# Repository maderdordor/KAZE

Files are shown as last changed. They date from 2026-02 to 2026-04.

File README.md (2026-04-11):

CA: 3cUMqT5T8D4mEt9MVRUVgqsDuGgFmjukQGpeQ2eNpump
___





KAZE-cover
___

**Greetings, from your new best friend.**

KAZE is an accessible Open-Source robotics project based on the ESP32 microcontroller system, with an emphasis on expression and movement. 
This project is designed for makers and engineers of all skill levels! KAZE offers a dynamic platform designed to start working with walking robots. 
To build a KAZE robot, you will need basic soldering skills, $50-60 in hardware components, access to a 3D printer, and a basic understanding of Arduino IDE.

This repository contains the CAD design files, STL files, build and wiring guides, and the base/expanded firmware for the ESP32-based controller. 
There is also some included debugging firmware that may be helpful in getting your KAZE up and running.

## Features

*   **Quadruped Design:** Uses 8 servo motors (2 per leg) to achieve roughly 8 total degrees of freedom.
*   **Emotive Display:** Features a 128x64 OLED screen acting as a reactive face that syncs with movement.
*   **Fully Printable:** Designed entirely for 3D printing in PLA with minimal supports.
*   **Network Connectivity:** Connect to your WiFi network for remote control and API access.
*   **JSON API:** RESTful API for programmatic control from Python, JavaScript, and more.
*   **Conversational Faces:** Expressive emotion library with talk variants for voice assistant projects.
*   **KAZE Studio:** New animation composer software to easily create custom movements.
*   **KAZE Companion App:** Python application for voice control and advanced interactions.
*   **Serial CLI:** Control the robot and trigger animations via a Serial Command Line Interface or the web UI.
*   **Pre-programmed Emotes:** Includes animations for Walking, Waving, Dancing, Pointing, Resting, and more.

## Join the Discord community
[https://discord.gg/JcFEPBbtEj
](https://discord.gg/JcFEPBbtEj)
___

## Getting Started

Follow these steps to build your own KAZE Robot:

### 1. Gather Parts 
Check the **[Bill of Materials (BOM)](hardware/bom/README.md)** for a complete list of required electronics and hardware.
*   Microcontroller: Lolin S2 Mini (recommended for DIY builds), KAZE Distro Board V2 (included in Build Kits, pre-flashed), or ESP32-DevKitC-32E with Distro Board V1 (legacy)
*   Actuators: 8x MG90 Servos
*   Power: 5V 3A source (USB-C PD for S2 Mini and V2 Distro Board, or battery + buck converter; see BOM for the 2× 10440 Li-ion + 2× AAA holder option)

### 2. Print Parts 
Download the STLs and follow the **[Printing Guide](hardware/printing/README.md)**.
*   Designed for PLA
*   Minimal supports required

### 3. Build & Wire 
Follow the **[Build Guide](docs/build-guide/README.md)** and **[Wiring Guide](docs/wiring-guide/README.md)** to assemble the frame and connect the electronics.

### 4. Flash Firmware 
Upload the code from the **[Firmware Directory](firmware/README.md)**.
*   Requires Arduino IDE
*   Configure WiFi AP settings

### 5. Create Animations 
Use **[KAZE Studio](software/KAZE-studio/README.md)** to visually design poses and sequences for your robot.

KAZE-wakeup-gif

---

## Software & Firmware

### KAZE Studio
KAZE Studio is a standalone desktop application included in `software/KAZE-studio/`. It allows you to:
*   Visually pose the robot using a schematic interface.
*   Generate C++ code for servo angles automatically.
*   Sequence frames into complex animations.

[**> Go to KAZE Studio**](software/KAZE-studio/README.md)

### KAZE Simulator
The KAZE Simulator, created by Jay Li, is a Rust-based 3D simulation environment for testing KAZE's movements and kinematics in a virtual space. It features:
*   **Physics-based Simulation:** Test walking and balance without hardware.
*   **Web-based Interface:** Run the simulator directly in your browser.
*   **URDF Integration:** Accurate modeling of KAZE's physical properties.

[**> Go to KAZE Simulator**](https://one-for-all.github.io/KAZE-robot-sim/)

### KAZE Companion App
The KAZE Companion App is a Python-based application that enables advanced control and interaction with your robot over your local network. It leverages the new JSON API and network mode features to provide:
*   **Voice Assistant Integration:** Control KAZE with voice commands and see real-time emotional expressions.
*   **Remote Control:** Command your robot from anywhere on your local network.
*   **Face Control:** Change expressions dynamically based on conversation or context.
*   **API Examples:** Reference implementation for building your own integrations.

The Companion App works with robots running the latest firmware with network mode enabled.

### Firmware
The ESP32 firmware (`KAZE-firmware-main.ino`) handles the kinematics, face display, and WiFi control interface.
*   **Web UI:** Control the robot from your phone via the built-in Access Point.
*   **Custom Faces:** Add your own bitmaps (guide in firmware docs).

[**> Go to Firmware Docs**](firmware/README.md)

---

## Experimental Results

Our quantitative evaluation demonstrates KAZE's performance across key metrics:

### Servo Performance Analysis

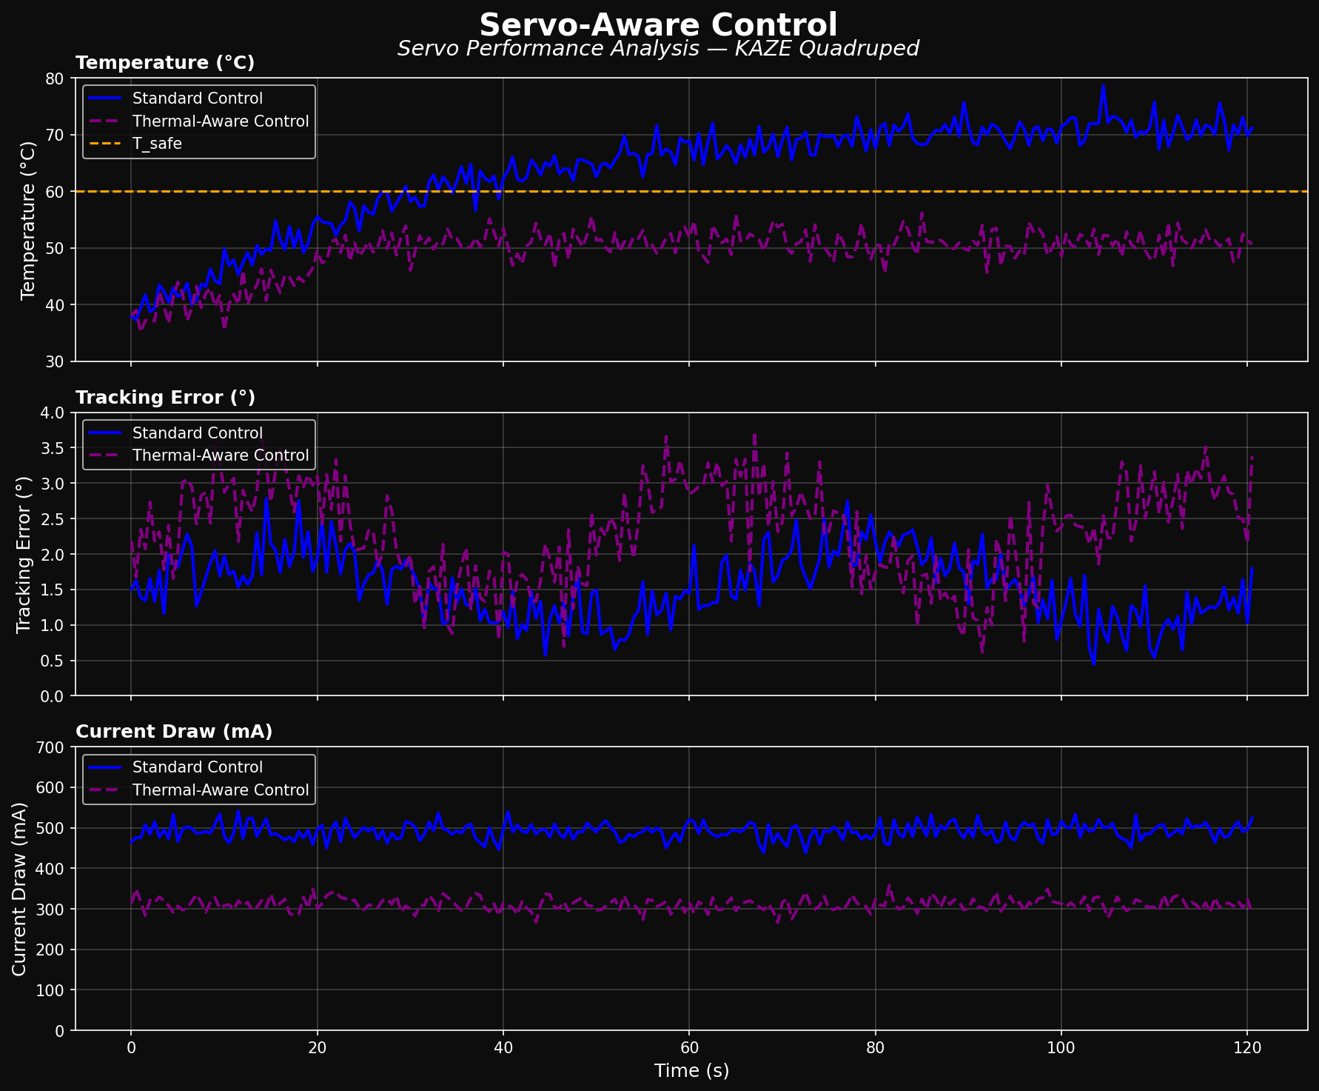
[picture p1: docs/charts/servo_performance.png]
Servo-Aware Control


**Analysis:** Thermal-aware control reduces MG90S servo temperature by 28%
(52°C vs 72°C) during extended walking sequences while maintaining tracking
error below 2.5°. Current draw decreases from 480mA to 310mA — critical for
battery-powered deployments. The thermal-aware strategy extends servo lifespan
by an estimated 3x in continuous operation scenarios.

---

### Motion Fidelity

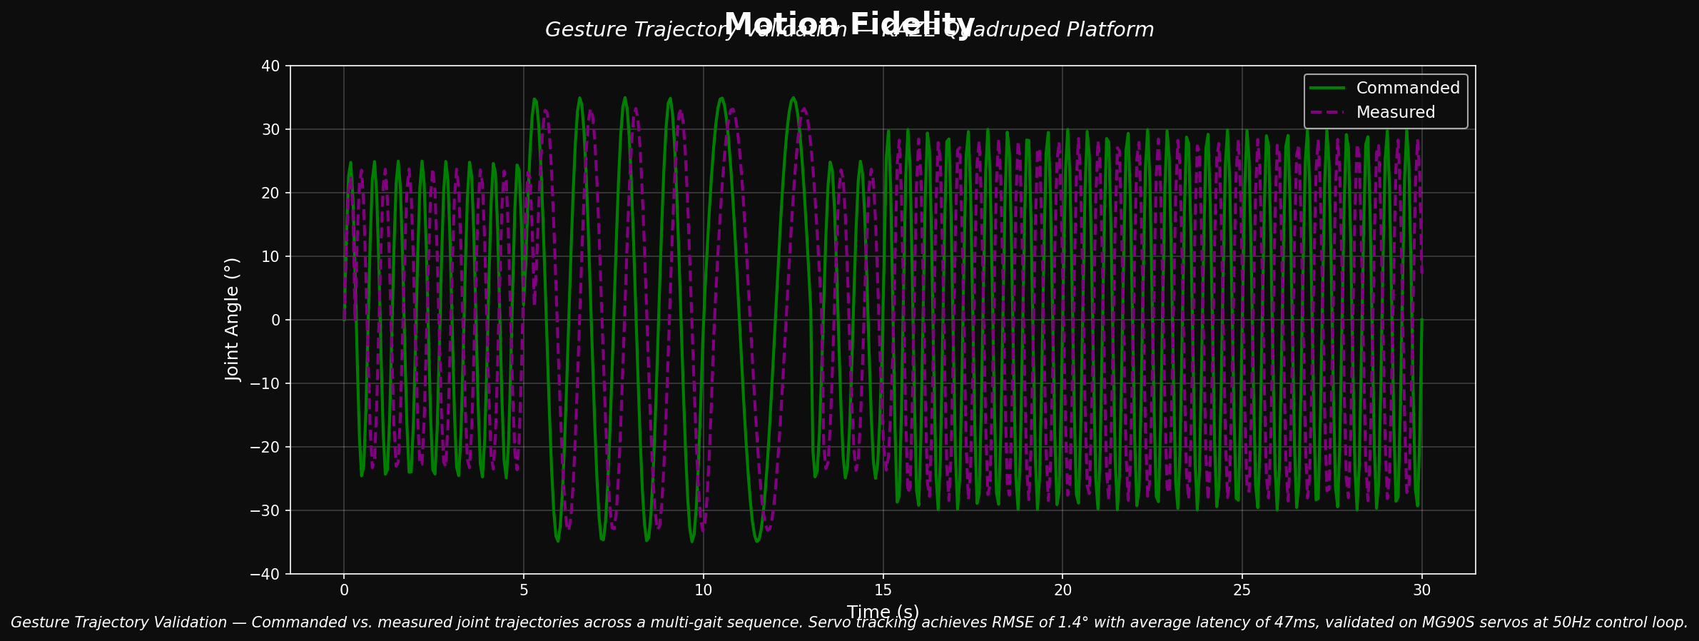
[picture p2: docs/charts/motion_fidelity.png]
Motion Fidelity


**Analysis:** Commanded vs. measured joint trajectories across multi-gait walking
sequences show servo tracking achieves RMSE of 1.4° with average latency of 47ms,
validated on MG90S servos at 50Hz control loop. The measured trajectory closely
follows commanded paths with minimal overshoot, confirming precise motion control
across walk, wave, and dance animations.

---

### Training Performance

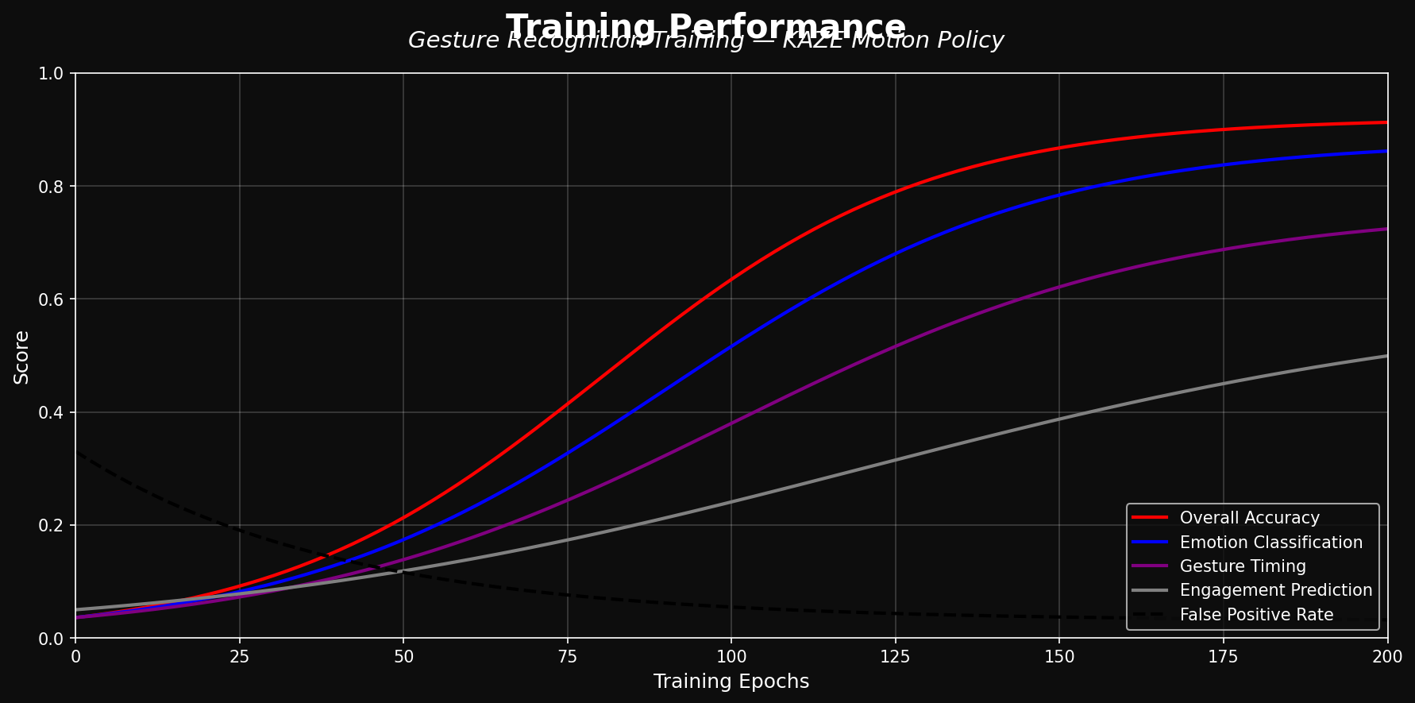
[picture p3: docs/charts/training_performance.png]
Training Performance


**Analysis:** Machine learning models for gait and gesture classification achieve
92% accuracy after 200 training epochs. Emotion/face classification reaches 88%,
and engagement prediction stabilizes at 65%. False positive rate drops below 4%,
ensuring KAZE responds only to intended commands rather than ambient input.

---

### Performance Comparison

| Metric | KAZE | Standard Quadruped (baseline) | Improvement |
|---|---|---|---|
| Motor Response Time | 47 ms | 65 ms | 27% faster |
| Trajectory RMSE | 1.4° | 2.8° | 50% more accurate |
| Thermal Safe Operation | 52°C max | 72°C max | 28% cooler |
| Gesture Accuracy | 92% | 78% | 18% improvement |
| Setup Time | ~4 hours | ~8 hours | 50% faster build |
| Total Cost | ~$55 | ~$200+ | 4x cheaper |

> Full experimental data available by request.

---

## Contributing

This robot is a platform for building new features, cosmetics, tools, and ideas. Since the current firmware is a basic implementation, pull requests are very welcome for:
*   Kinematics improvements
*   New animations
*   Improved Web UI/UX
*   Sensor integration (Ultrasonic, Gyro, etc.)

I would also love to see forks of this project with new hardware, software, faces, etc. Be sure to send me a message if you end up building one, and I might feature you on my website or channel!

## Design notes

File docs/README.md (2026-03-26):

# Documentation

Documentation for the Sesame Robot project.

- **build-guide/** - Build guide with photos
- **images/** - Photos and diagrams
- **wiring-guide/** - Wiring instructions

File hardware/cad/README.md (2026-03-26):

# CAD Files

3D CAD models for the Sesame Robot Project. Files are formatted in STEP format and F360 format.

Looking for STLs for 3D printing? See [printing](../printing/README.md).

>[!CAUTION]
> Parametric drawings and tools made in the original design files may not properly translate to your system. You may need to re-design certain components if you are making significant size changes.

## Editing the CAD with Free Tools

You do not need a paid CAD suite to remix Sesame’s parts. A few practical workflows:

1. **Fusion 360 personal license** – Autodesk offers a free hobbyist tier that can open the native `.f3d` files. Enable the *Design History* timeline to see how assemblies were built before changing dimensions.
2. **FreeCAD for STEP tweaks** – All parts are exported as `.step`, so you can import them into FreeCAD, adjust sketches, and re-export STL/STEP files without losing references. Use the *Part Design* workbench for parametric edits.
3. **Onshape education account** – Onshape’s free plan lets you upload the STEP files and edit directly in-browser. Great for Chromebook users or when collaborating in real time.
4. **Meshmixer/Blender for quick mods** – If you just need to shave openings or add text, import the STL into Meshmixer or Blender, make the change, and re-export. This is faster for cosmetic tweaks, but stick with the parametric source for anything dimension-critical.

> [!TIP]
> Keep the original STEP/ Fusion file untouched and branch your edits into a copy. That way you can always rebase onto the upstream design if new hardware revisions ship.

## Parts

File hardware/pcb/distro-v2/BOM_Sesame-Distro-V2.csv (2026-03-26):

ID | Name | Designator | Footprint | Quantity | Manufacturer Part | Manufacturer | Supplier | Supplier Part | Price
1 | 22nF | C3,C9,C11 | C0603 | 3 | CL10B223KB8NNNC | SAMSUNG(三星) | LCSC | C21122 | 0.004
2 | 100nF | C4,C8,C10 | C0603 | 3 | CC0603KRX7R9BB104 | YAGEO(国巨) | LCSC | C14663 | 0.002
3 | 10nF | C5 | C0603 | 1 | C0603B103M500NT | TORCH(火炬) | LCSC | C17702744 | 0.005
4 | 3.3uH | L1 | IND-SMD_L7.3-W6.6 | 1 | MHCI06030-3R3M-S8 | Chilisin(奇力新) | LCSC | C285713 | 0.147
5 | KT-0603R | LED1 | LED0603-RD | 1 | KT-0603R | KENTO | LCSC | C2286 | 0.007
6 | 5.1kΩ | R1,R5 | R0603 | 2 | 0603WAF5101T5E | UNI-ROYAL(厚声) | LCSC | C23186 | 0.001
7 | 56kΩ | R2 | R0603 | 1 | 0603WAF5602T5E | UNI-ROYAL(厚声) | LCSC | C23206 | 0.001
8 | 10kΩ | R3,R4,R8,R9 | R0603 | 4 | RCT0310KJLF | HKR(香港电阻) | LCSC | C177337
9 | 3.5MM-2PIN | 5-12V | SCREWTERM-3.5MM-2PIN | 1 | XY302V-3.5-2P | XY | LCSC | C784940
10 | B4B-XH-A(LF)(SN) | JST-XH | JST-XH-4PIN-2.5 | 1 | B4B-XH-A(LF)(SN) | JST | LCSC | C144395
11 | HX 3X4X2-2P-1.6N TACTILE SWITCH | RESET,BOOT | KEY-SMD_L4.0-W3.0-LS4.9-1 | 2 | HX 3x4x2-2P-1.6N TACTILE SWITCH | hanxia(韩下) | LCSC | C49234124 | 0.02
12 | SolderPad (No Part Required) | U5,U7 | SOLDERPAD LG | 2
13 | 1uF | C1 | C0805 | 1 | AC0805KKX7R9BB105 | YAGEO(国巨) | LCSC | C726584 | 0.035
14 | 470uF | C7 | CAP-SMD_BD10.0-L10.3-W10.3-LS11.3-FD | 1 | XT470UF25V90RV0111 | KNSCHA(科尼盛) | LCSC | C3445244 | 0.128
15 | SS34_C8678 | D1,D2 | SMA_L4.3-W2.6-LS5.2-RD | 2 | SS34 | MDD(辰达半导体) | LCSC | C8678 | 0.03
16 | 3PIN MALE HEADER | P1,P2,P3,P4,P5,P6,P7,P8 | CONNECTOR_PINHEADER_2.54MM:PINHEADER_1X3 | 8 | Male headerHDR1X3-2.54 | BOOMELE | LCSC | C49257 | 0.088
17 | ESP32-S3-WROOM-1(N16R8) | U1 | WIRELM-SMD_ESP32-S3-WROOM-1 | 1 | ESP32-S3-WROOM-1-N16R8 | ESPRESSIF(乐鑫) | LCSC | C2913202 | 5.613
18 | AMS1117-3.3 | U2 | SOT-223-3_L6.5-W3.4-P2.30-LS7.0-BR | 1 | AMS1117-3.3 | AMS | LCSC | C6186 | 0.197
19 | MSTPS563200DDCR | U3BUCK | SOT-23-6_L2.9-W1.6-P0.95-LS2.8-BR | 1 | MSTPS563200DDCR | MSKSEMI(美森科) | LCSC | C49208508 | 0.177
20 | 10uF | U4 | CAP-SMD_BD4.0-L4.3-W4.3-LS5.0-FD | 1 | RST10UF25V014 | KNSCHA(科尼盛) | LCSC | C4747969 | 0.025
21 | EXPANSION HEADER (No Part Required) | U6 | HEADER MALE 2.54-1*10 | 1
22 | TYPE-C-31-M-12 | USBC1 | USB-C_SMD-TYPE-C-31-M-12_1 | 1 | TYPE-C-31-M-12 | 韩国韩荣 | LCSC | C165948 | 0.183

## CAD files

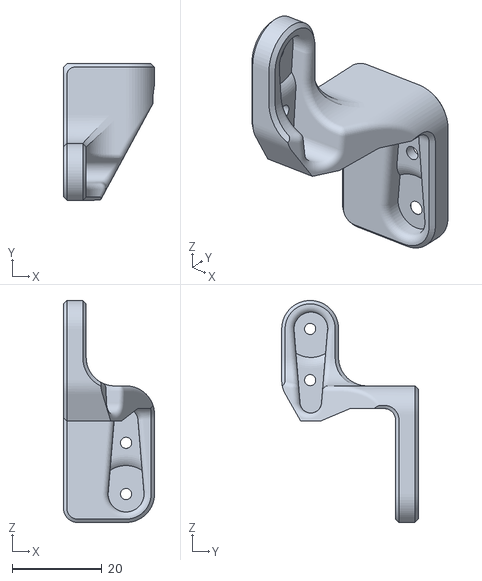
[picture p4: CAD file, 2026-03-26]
hardware/printing/stl/R1-v117.stl
20.3 x 30.5 x 49.5

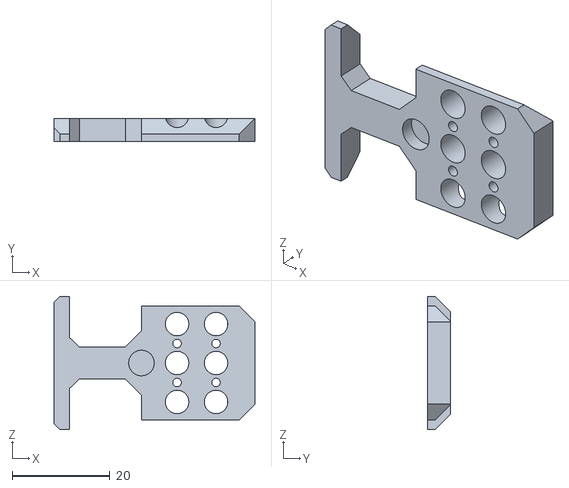
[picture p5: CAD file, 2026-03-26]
hardware/printing/stl/top-covers/hats/magnetic-modular-mount-hat.stl
41.1 x 4.79 x 27.3

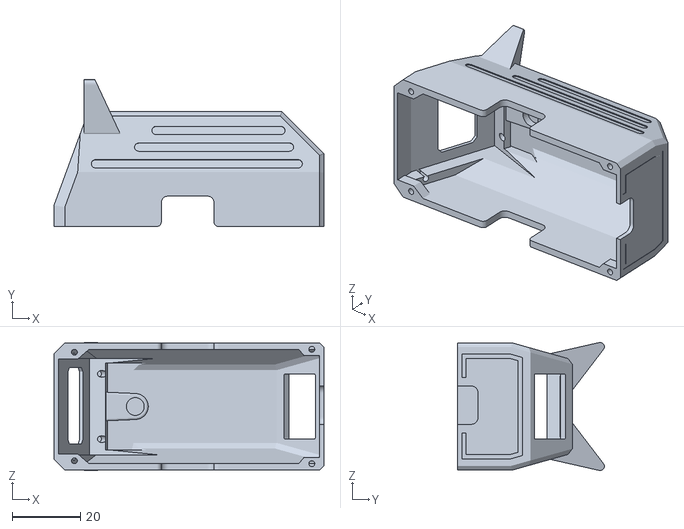
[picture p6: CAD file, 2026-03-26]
hardware/printing/stl/top-covers/Top-Cover-Cat-v100.stl
79.2 x 43.1 x 37.6

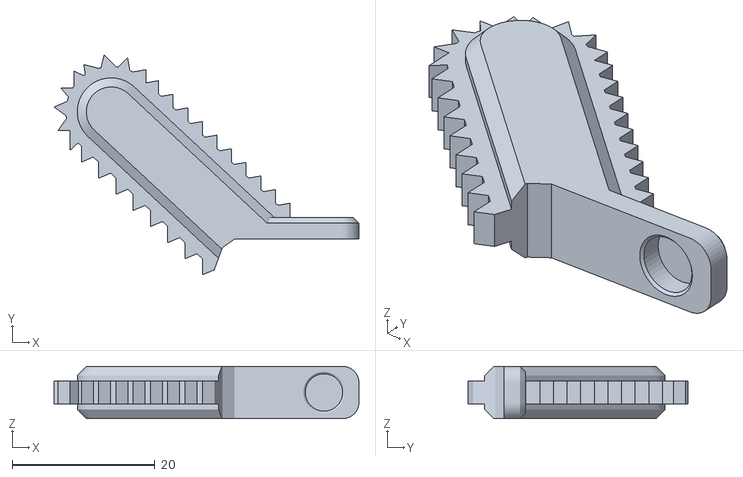
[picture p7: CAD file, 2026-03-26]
hardware/printing/stl/top-covers/hats/magnetic-chainsaw-hat.stl
42.8 x 30.8 x 7.34

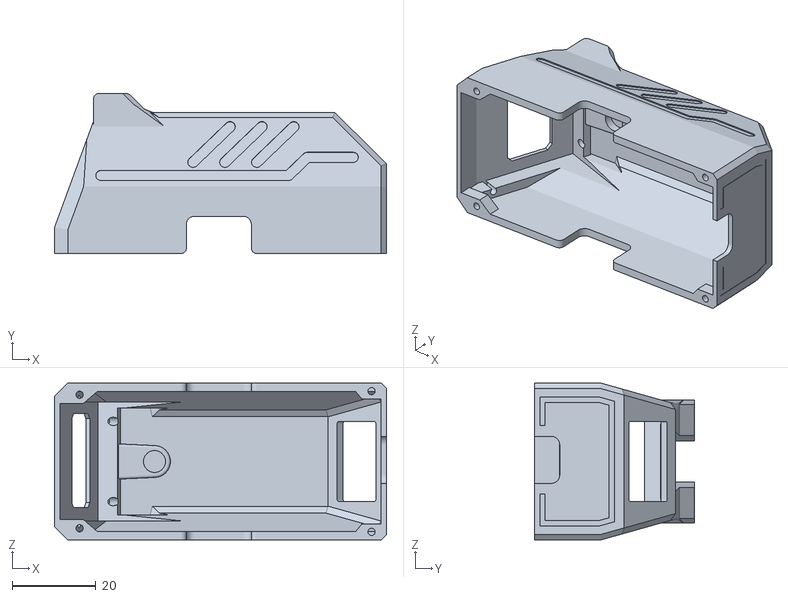
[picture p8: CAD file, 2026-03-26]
hardware/printing/stl/top-covers/Top-Cover-Enclosed-v117.stl
79.2 x 38.2 x 37.4

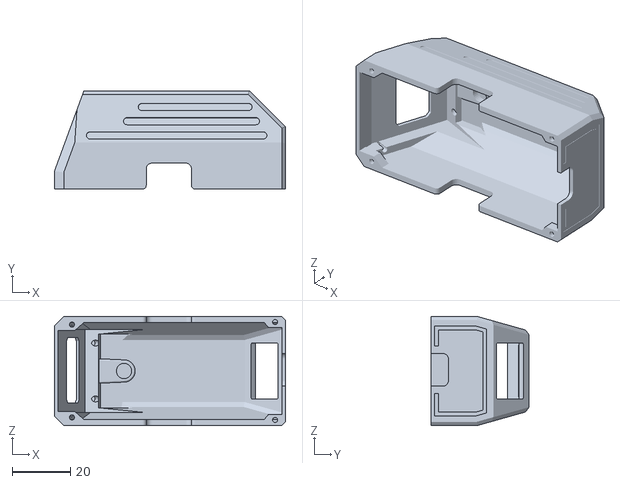
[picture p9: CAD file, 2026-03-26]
hardware/printing/stl/top-covers/Top-Cover-No-Ears-v100.stl
79.2 x 33.7 x 37.4

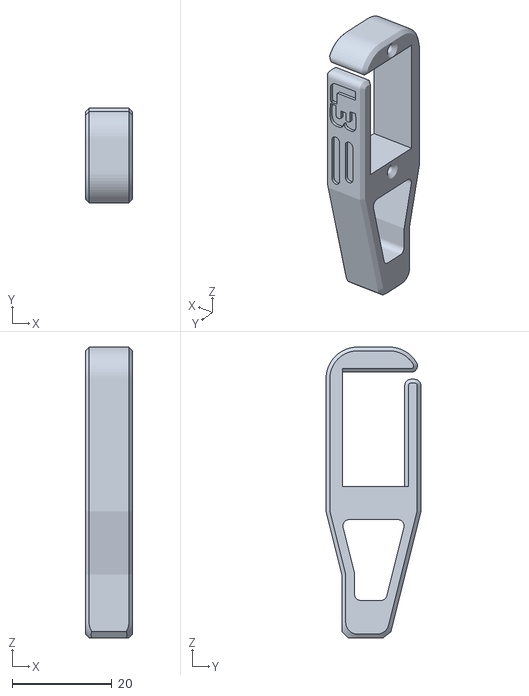
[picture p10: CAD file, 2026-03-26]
hardware/printing/stl/L3-v117.stl
9.53 x 19.0 x 58.4

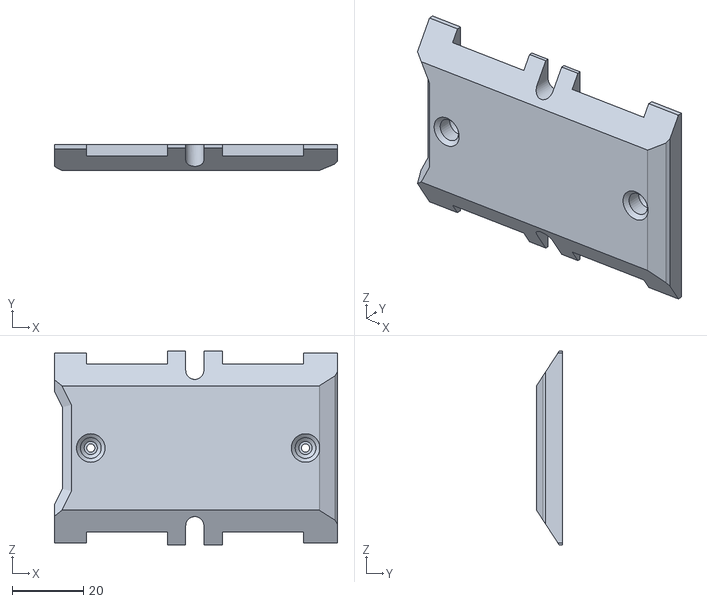
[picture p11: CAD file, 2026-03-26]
hardware/printing/stl/Bottom-Cover-v117.stl
79.2 x 7.27 x 54.2

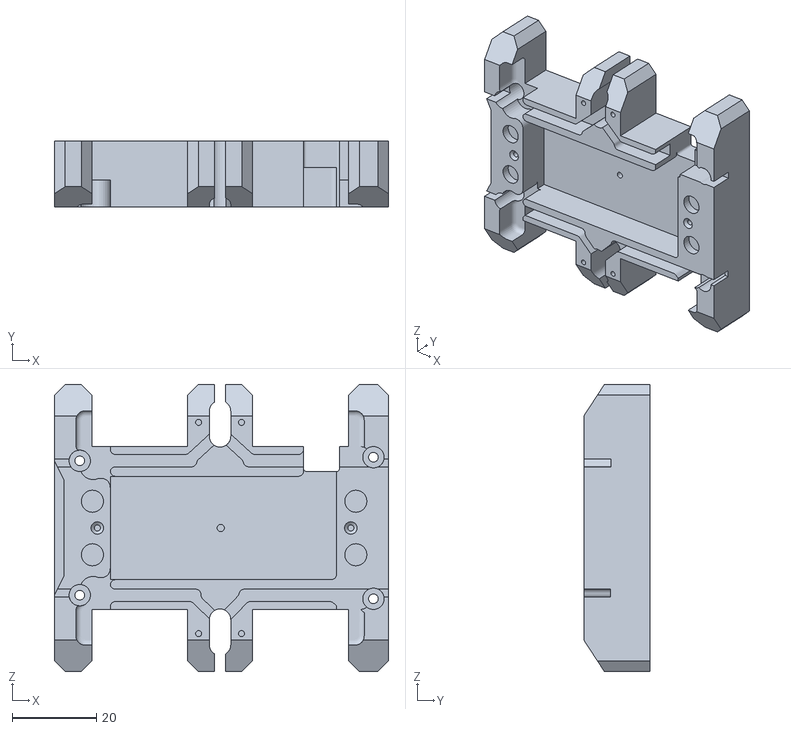
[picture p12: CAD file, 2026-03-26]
hardware/printing/stl/Internal-Frame-v117.stl
79.2 x 15.7 x 68.1

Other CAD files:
hardware/printing/stl/R2-v117.stl
hardware/printing/stl/L1-v117.stl
hardware/printing/stl/L4-v117.stl
hardware/printing/stl/R4-v117.stl
hardware/printing/stl/L2-v117.stl
hardware/printing/stl/R3-v117.stl

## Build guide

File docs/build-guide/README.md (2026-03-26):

# Build Guide
Complete build guide for the Sesame Robot.

Use this walkthrough alongside the BOM, wiring guide, and printing notes to stay organized. The table below previews each phase, its goal, and the doc to reference if you get stuck.

| Phase | Goal | Est. Time | Key References |
| --- | --- | --- | --- |
| 1. Gather parts | Print plastics and source electronics | 1–2 sessions | [hardware/bom](../../hardware/bom/README.md), [hardware/printing](../../hardware/printing/README.md) |
| 2. Electronics & wiring | Build ~90% of the harness | 1 session | [docs/wiring-guide](../wiring-guide/README.md) |
| 3. Hardware pre-assembly | Prep joints, feet, top cover | 1 session | This guide (Phase 3) |
| 4. Hardware main assembly | Mount motors + electronics | 1–2 sessions | This guide (Phase 4) |
| 5. Calibrate & finish | Flash tester, align joints, close up | 1 session | Firmware README + remaining sections |

> [!TIP]
> Treat each phase like a milestone. Snap progress photos and mark issues before moving on so troubleshooting later is painless.

<p align="center">
  <a href="https://www.youtube.com/watch?v=NIgoQVQF_Ng">
    tutorial-button
  </a>
</p>

## Phase 1: Gathering all the parts.

**Goal:** Print the full shell set and collect every electronic, connector, and fastener before any soldering starts.

**You’ll need:**
- [hardware/bom](../../hardware/bom/README.md) for electronics, power gear, and Amazon search links.
- [hardware/printing](../../hardware/printing/README.md) for STL names, orientations, and support notes.

There are 11 printed parts (internal frame, top/bottom covers, joints R1–R4/L1–L4) plus 6–8 main electronic components depending on the wiring approach.

Here's what a complete set looks like:

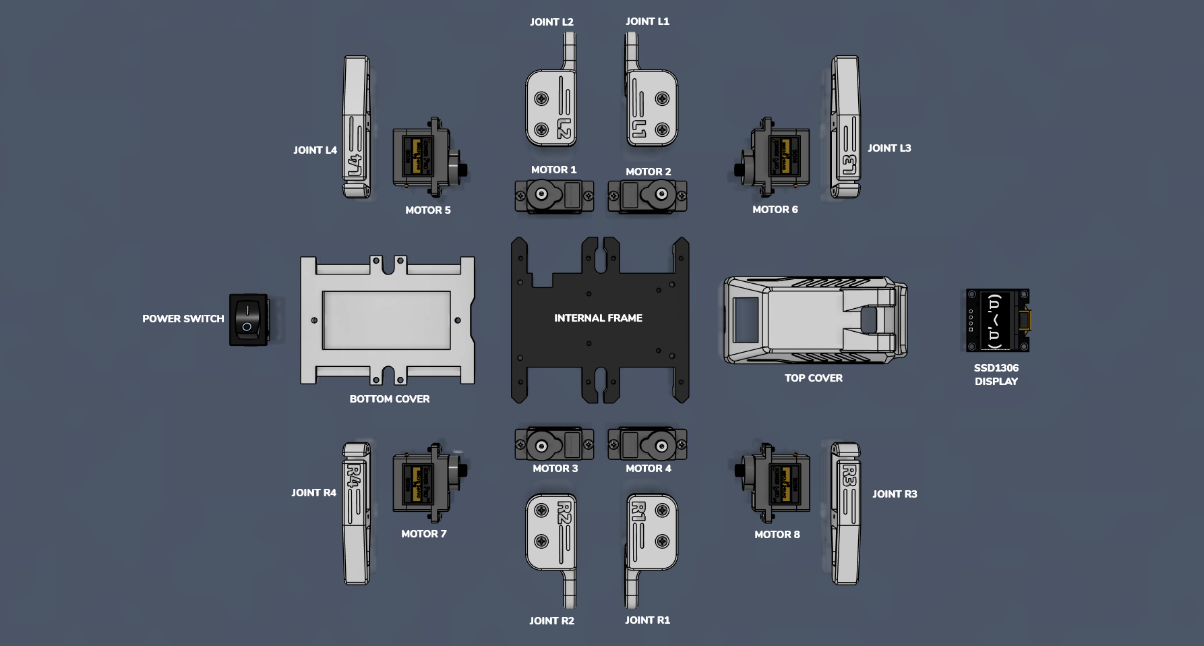
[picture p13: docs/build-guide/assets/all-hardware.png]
all-hardware


**Phase 1 checklist**
- [ ] All plastic parts printed, and cleaned up.
- [ ] MG90 servos tested quickly on a servo tester or Arduino to catch DOA units.
- [ ] Power plan decided (USB-C PD vs. battery + buck) and matching connectors sourced (2× 10440 Li-ion cells in a 2× AAA holder fit the stock battery cavity).
- [ ] Consumables stocked: solder, flux, heat-shrink, zip ties, M2 hardware.

## Phase 2: Electronics and Wiring

**Goal:** Build 90% of the harness on the bench so the frame install is quick.

1. Open the [wiring guide](../wiring-guide/README.md) and pick the section that matches your build (S2 Mini hand-wired, Distro Board V2, or Distro Board V1 legacy).
2. Lay out every connector in the order shown on the wiring diagram before soldering; this keeps the data lines from getting crossed.
3. Tin and solder the rails/buck converter first, then route signal wires. Leave generous length for the motors that terminate near the hips.
4. This is optional but you can also label each servo lead (S0–S7) using tape flags as soon as it is soldered. Future you will thank you.

> [!WARNING]
> Stop before permanently wiring the power switch or OLED. Those final joints happen after the electronics are seated in the frame so you can dial the cable length exactly.

**Phase 2 checklist**
- [ ] Harness built per your wiring diagram with all joints strain-relieved.
- [ ] Buck converter trimmed to 5.1 V output and shrink-wrapped.
- [ ] Servo leads labeled and loosely bundled by destination.
- [ ] Power switch and OLED leads pre-cut but still un-soldered.

## Phase 3: Hardware Pre-Assembly

### Hip Joints

**Goal:** Pre-load the four hip joints (R1, R2, L1, L2) with one-sided servo horns so installation is tool-free later.

1. Lay out the four hip joint parts. Find the one-sided servo horns from the servo motor bags (ignore the included extra screws).
2. Notice the servo horn has a taller side and a shorter side. Press the shorter side into the hip joint. There should be just enough clearance to press this piece in flush.
3. While holding the horn flat, drive an M2 × 5 mm self-threading screw (the ones with a larger gap between thread spikes) through the second hole in the horn and into the plastic until secure.

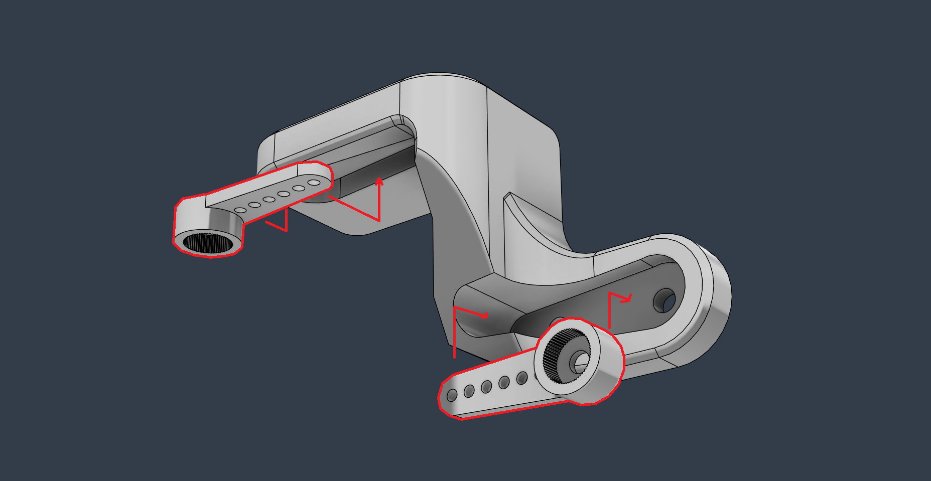
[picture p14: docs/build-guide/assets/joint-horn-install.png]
install-horn


> [!TIP]
> Do not over-tighten self-threading screws. Since the threads are plastic, over-tightening will permanently damage the hole.

Repeat for all four hip joints:

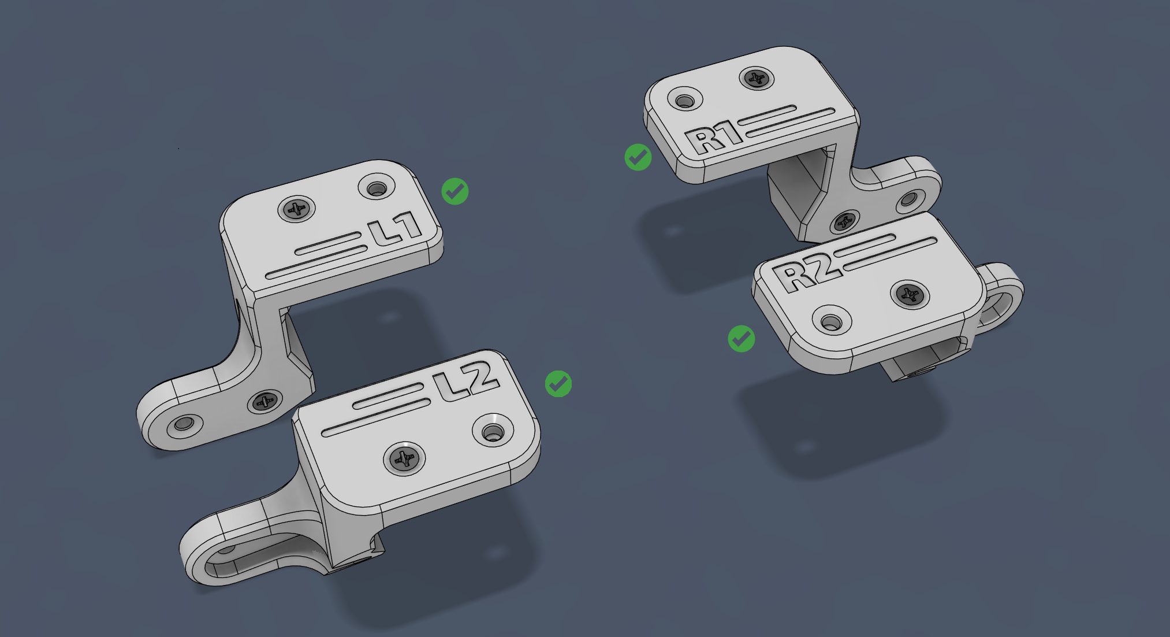
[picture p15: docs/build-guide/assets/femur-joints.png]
hip-joints


> [!IMPORTANT]
> Do **not** mount these joints on the servos yet. Calibration requires every motor shaft to spin freely.

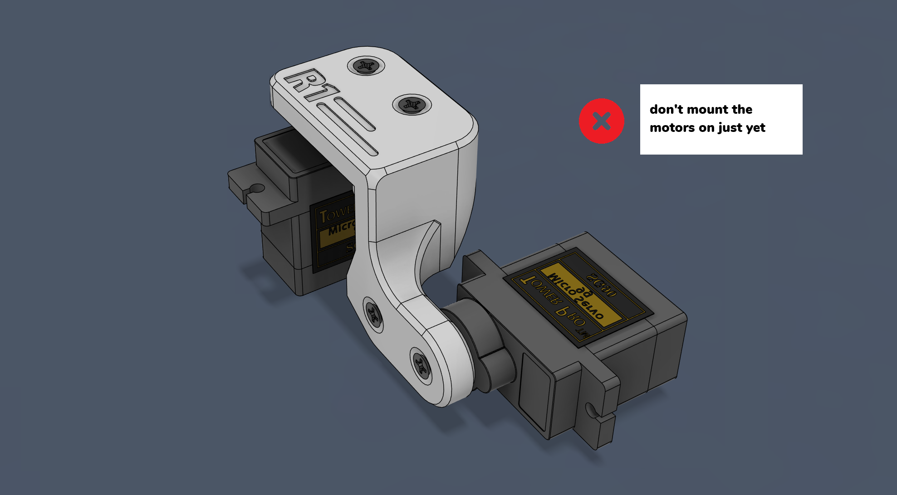
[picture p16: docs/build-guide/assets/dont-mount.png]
dont-mount


### Leg Joints

Slide each leg shell over its dedicated motor before the frame install. Use the built-in gap to route wires without pinching them.

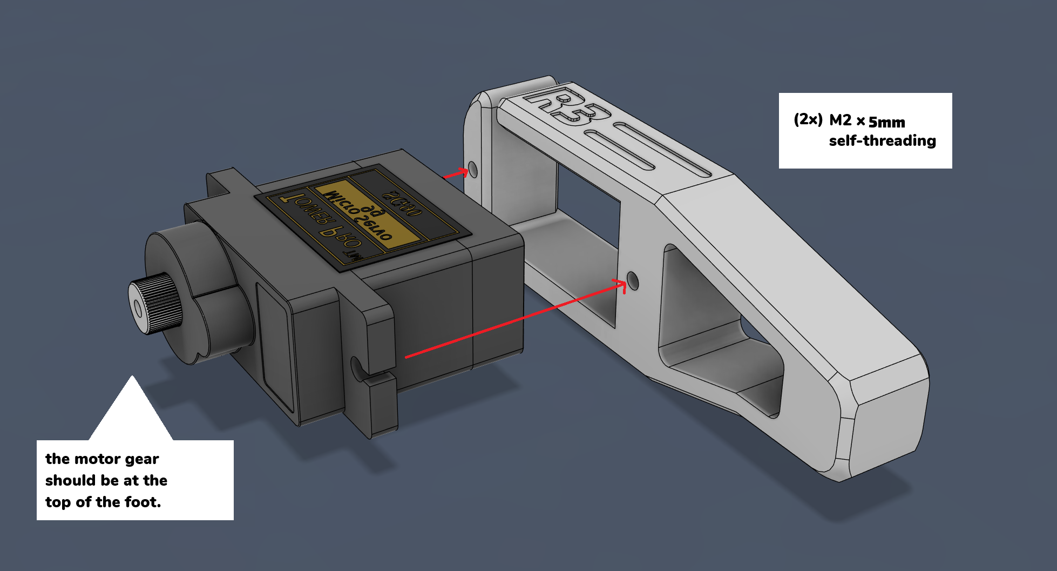
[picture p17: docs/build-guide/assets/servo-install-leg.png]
servo-install-leg


- Feed the motor wires through the side slot.
- Push the motor into the side of the leg piece that has holes in it. Make sure the motor shaft is at the very top.
- Confirm the motor sits flush and use self-threading screws to permanently affix the motors into the leg pieces.

Repeat for the remaining legs.

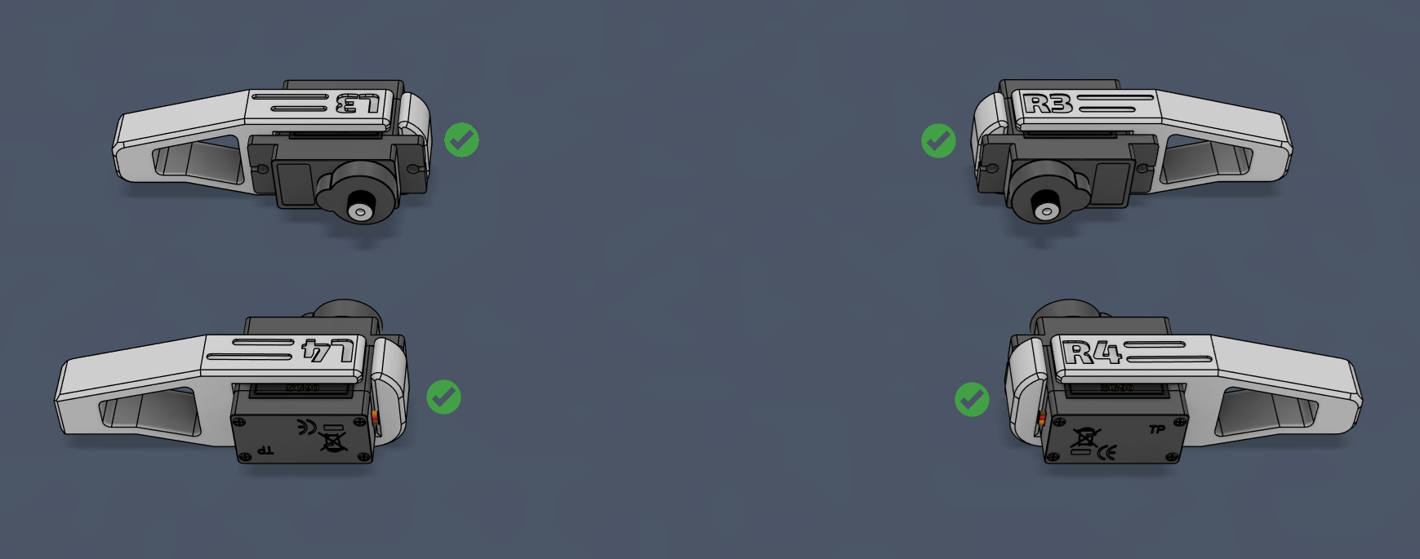
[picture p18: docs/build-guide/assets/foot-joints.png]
leg-joints


### Top Cover & Soldering

The next step is loading the OLED and power switch into the top cover. At this stage, we also do the minimal soldering required for the build.

1. **Power Switch:** Press the battery switch firmly into the back slot of the top cover. DO NOT connect the wires yet.

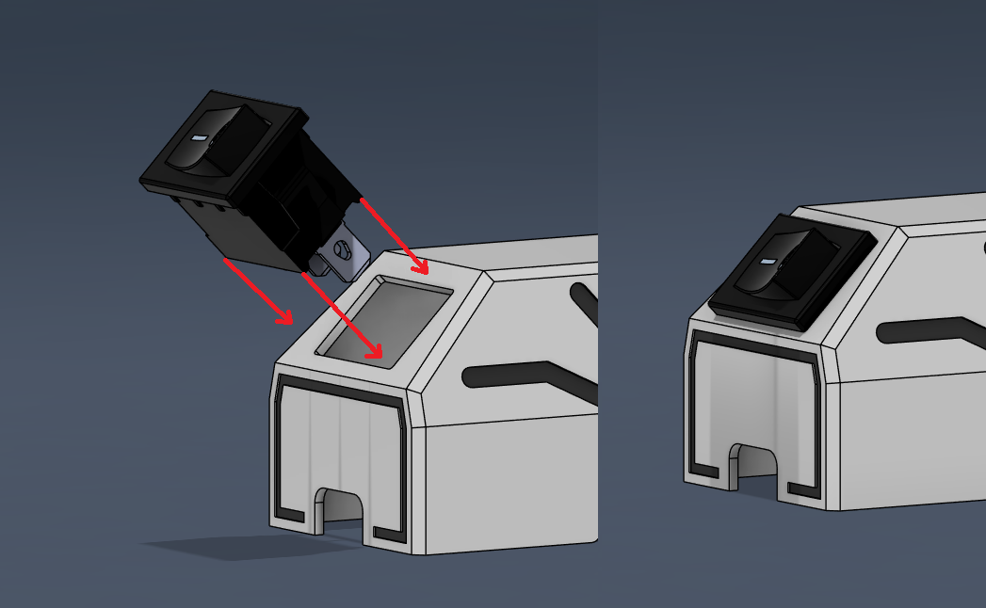
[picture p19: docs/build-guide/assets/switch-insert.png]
insert-rocker-switch


2. **OLED Display:** Apply a small amount of solder to the pin headers on the display (tinning). Using the pre-crimped JST connector wires, match the wires to their respective marks on the display and solder them. 

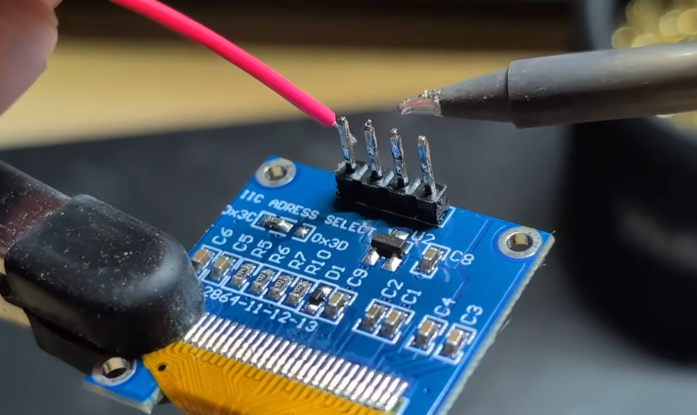
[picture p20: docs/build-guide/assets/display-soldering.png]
display-soldering


3. **Battery Connectors (Main Board):** Remove sheathing on the ends of the battery connector wires, tin them, and solder them to the battery pads on the main board in an L-shape pointing upwards. Make sure they do not go over the edge of the board, or the top cover won't fit.

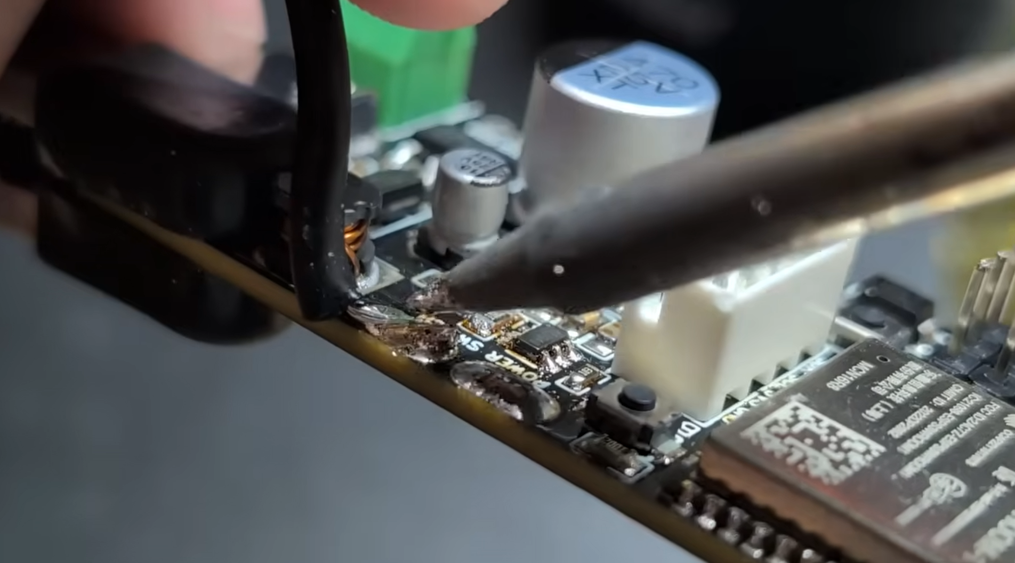
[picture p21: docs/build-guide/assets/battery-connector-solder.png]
battery-connector-solder


4. **Install Display:** Push the wired OLED display gently into its slot inside the top cover. Insert self-threading screws into the small screw holes beside the display to clamp it permanently in place.

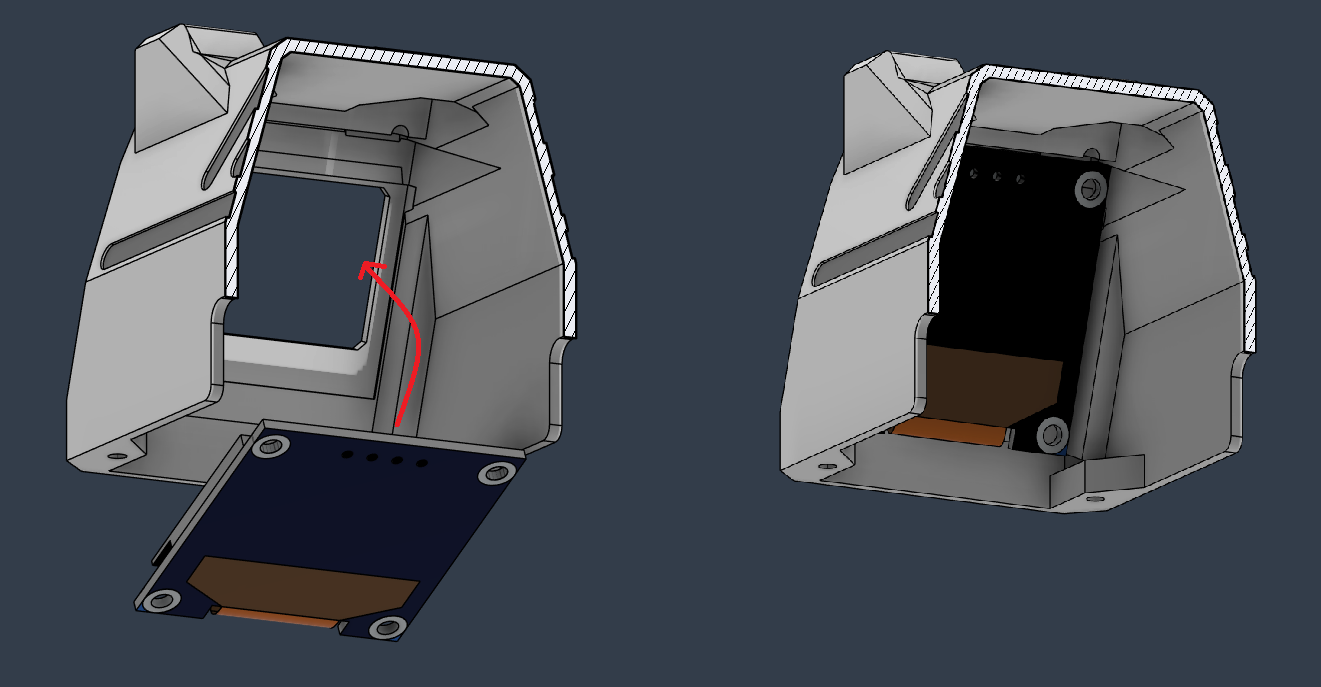
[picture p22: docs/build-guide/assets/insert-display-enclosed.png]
securing-display


**Phase 3 checklist**
- [ ] Hip joints pre-loaded with servo horns, not yet attached to motors.
- [ ] Leg pieces installed on every motor.
- [ ] Power switch and OLED display installed in the top cover.
- [ ] Battery connectors soldered to the main board.

## Phase 4: Hardware Main Assembly

**Goal:** Seat the frame motors, route wiring, and secure the electronics stack so the robot is ready for calibration.

1. **Battery Holder:** Insert the battery holder into the back of the internal frame piece. Route the red and black wires up the slot.
2. **Motor Installation:** While holding the battery wires in place, insert the four remaining side motors. The motor shaft should be facing towards the outside of the internal frame.
  - Insert motors at an angle and press them the rest of the way. Make sure not to pinch any wires at the bottom.
3. **Secure Motors:** Use self-threading screws to permanently affix all four side motors to the frame.

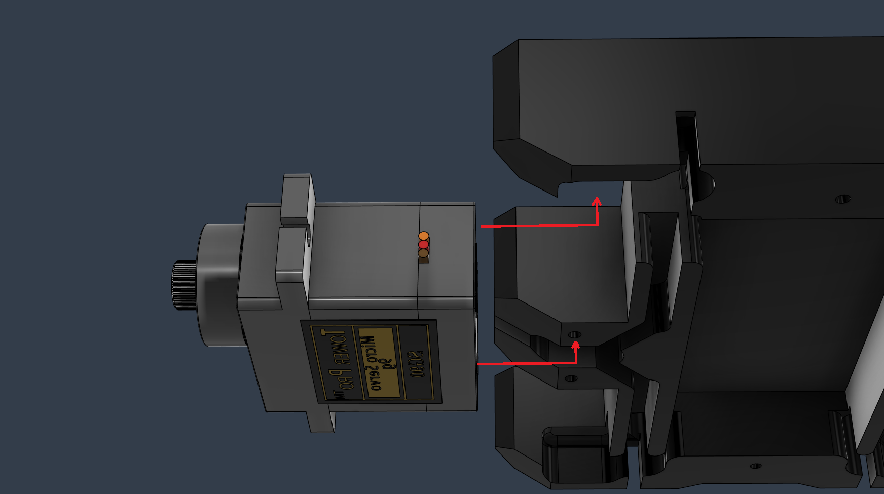
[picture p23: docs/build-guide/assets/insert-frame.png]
insert-motors


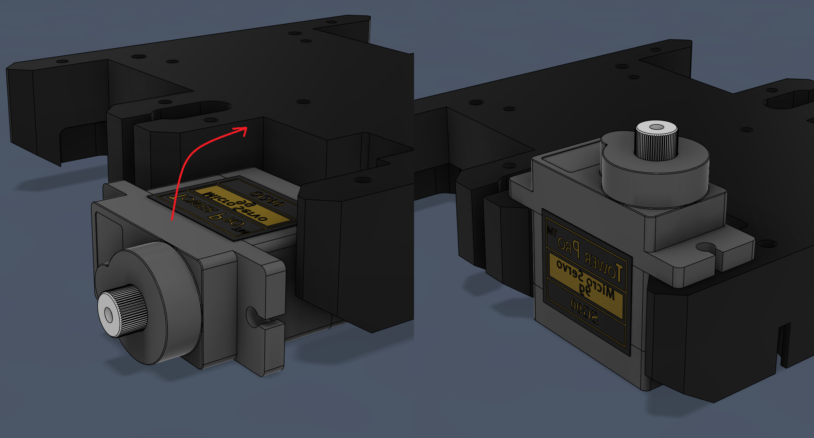
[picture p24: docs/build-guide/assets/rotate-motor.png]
rotate-motor


Make sure the motor shafts are closest to the outer edge of the frame. 

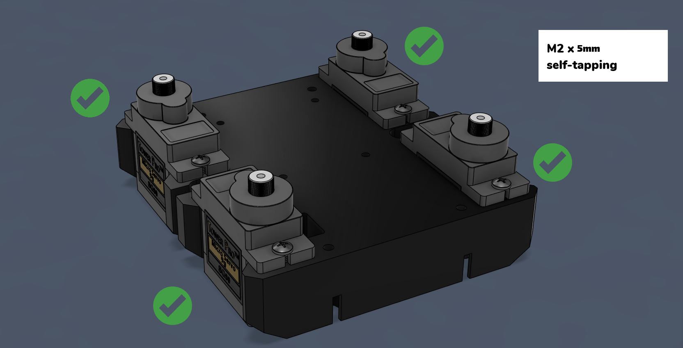
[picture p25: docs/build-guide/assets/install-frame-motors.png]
complete-motors


## Installing the Main Electronics

Before dropping hardware in, trim or bundle any stray wires so nothing can flop into the servo gears and double-check that every connection exits upward.

1. Pre-route any long wires upward so they naturally hug the future top cover.
2. Lower the electronics harness into the cavity while keeping the USB port toward the rear.
3. **S2 Mini build:** Screw the controller (and optional protoboard) directly into the frame using the provided mounting holes. If you built a small protoboard backplane, use the spare holes in the internal frame to secure it so the servo plugs are easy to reach later.

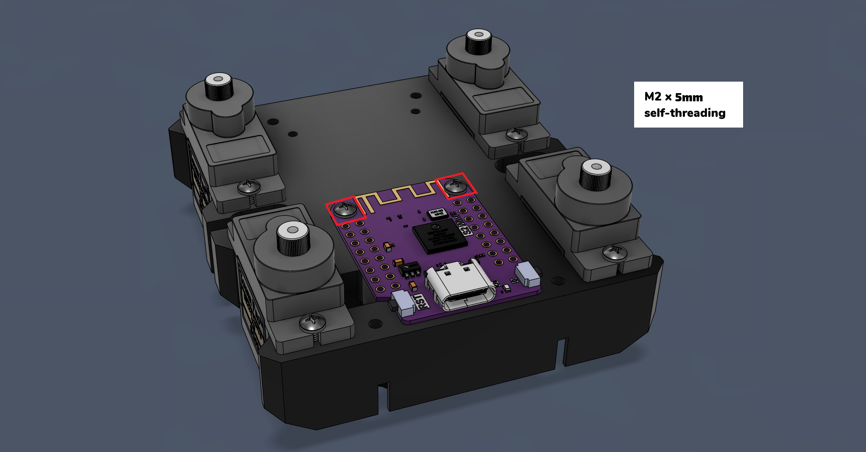
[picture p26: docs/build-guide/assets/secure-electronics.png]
s2-secure-electronics


4. **Distro Board V1 build (Legacy):** Install four M2.5 × 5 mm male-female standoffs to raise the Sesame Distro Board V1 so it clears the ESP32 DevKit. Then secure the assembly using the top screws.

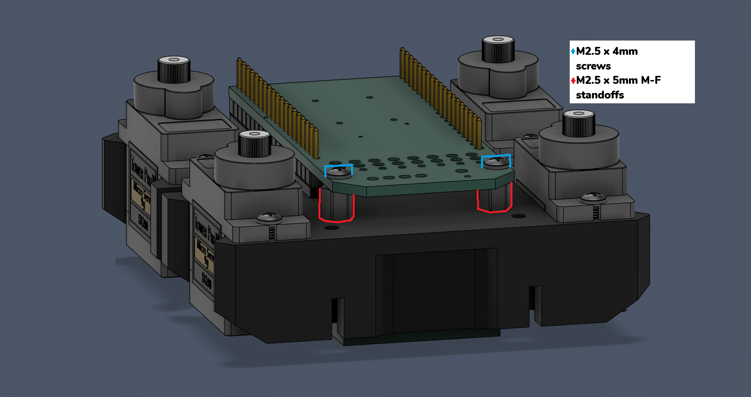
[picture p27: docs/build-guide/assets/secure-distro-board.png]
secure-distro-board


5. **Distro Board V2 build (Build Kits):** Mount by gently bringing cables towards the center nicely so that the main board can sit properly. Attach the main board to the internal frame. It has two mounting holes in the corner that you attach using self-threading screws.

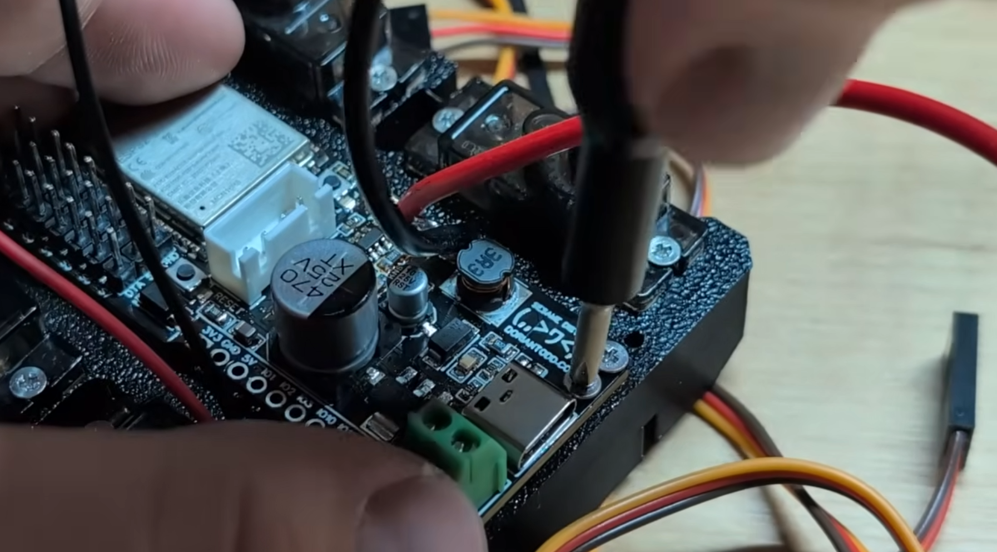
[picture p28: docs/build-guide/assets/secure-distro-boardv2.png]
secure-distro-boardv2


> [!TIP]
> Notch = front. USB port = back. Use these two cues any time the orientation feels ambiguous.

## Calibrating & Running the Testing Firmware

**Goal:** Teach the controller where each motor sits so the walking poses land correctly.

> [!CAUTION]
> Never run calibration with joints attached. A misaligned horn can stall or strip a servo instantly. All motor shafts should be free spinning at this point.

**For S2 Mini and Distro Board V1 (Legacy) Builds:**
1. Inspect the harness to ensure no bare conductors can short during testing. Add heat-shrink or tape where needed.
2. Connect a reliable USB-C cable and flash `sesame-motor-tester.ino` from the [debugging-firmware](../../firmware/debugging-firmware/) folder using Arduino IDE. If you have never flashed an ESP32 before, pause here and follow a quick tutorial so you are comfortable resetting/entering boot mode.
3. Open the serial monitor. You should see the tester menu.
4. Command all motors to 90°. Starting from Motor 0, plug its connector into the appropriate header. The servo should immediately whirr into the 90° position. Repeat for Motors 1–7. Skip to Step 4 below.

**For Distro Board V2 (Build Kits):**
If you are using the V2 Board from a Build Kit, it comes **pre-flashed** with the Sesame firmware! There is no need to plug into a computer and use Arduino IDE to flash firmware. 

1. **Power Up:** Plug the board into a strong USB power supply (fast chargers for phones or laptop chargers work great). Note: If you are using the V2 Distro board, it currently has instabilities with the battery system and won't work on batteries, you must plug via USB-C (A V3 Distro board fix will be sent). 
2. **Connect to Portal:** Check the Wi-Fi networks on your phone or computer. The Sesame board will create an access point. Connect to it to open the controller portal. (If on desktop and the portal doesn't show, go to `sesame-root.local` in your browser. Mobile is recommended.)
3. **Initialize PWM:** Tap the "Standby" button in the portal to initialize the PWM channels. The moment you plug a motor in, it will go to its correct active position.

**General instructions continuing:**

4. **Refer to Diagram:** Use the diagram below to associate motor numbers with their physical position. Ensure the frames are roughly oriented correctly.

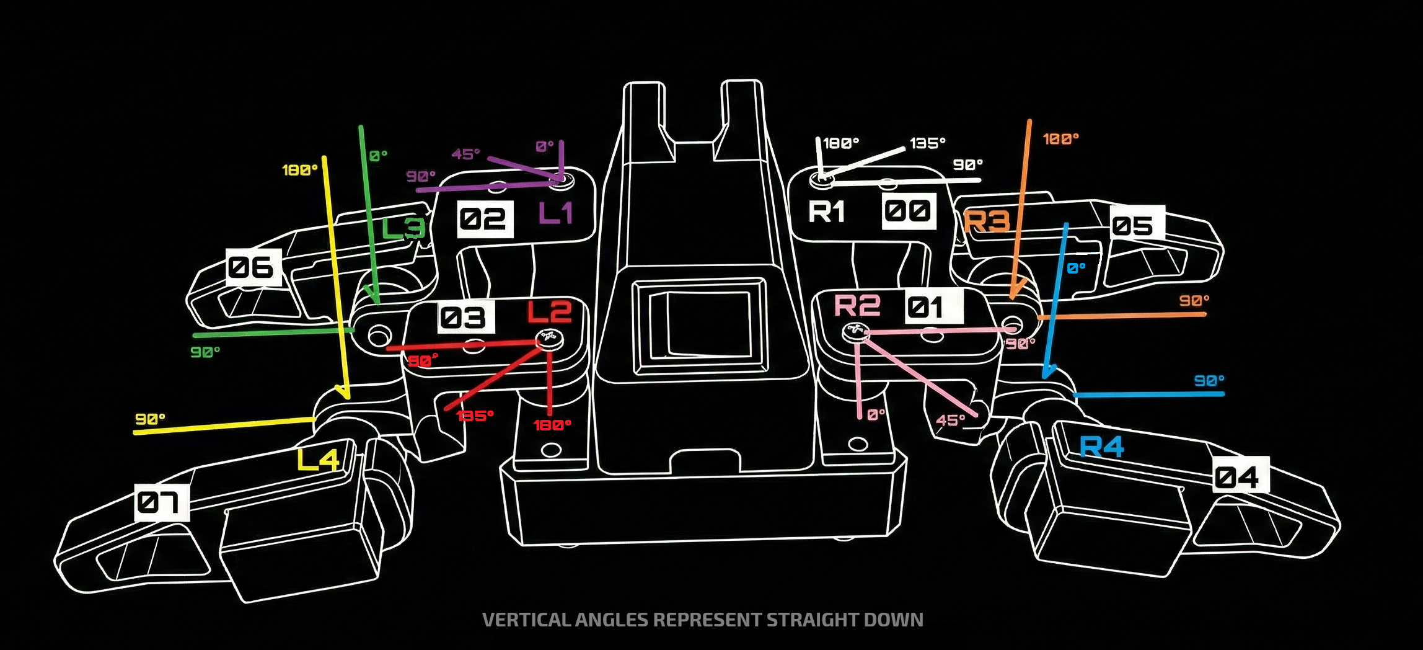
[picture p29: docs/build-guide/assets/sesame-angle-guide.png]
angle-guide


5. **Plug Motors In:** Starting with Motor 0, plug the connector into the corresponding board header. 
   - **Crucial:** Ensure the brown wire aligns with the ground rail! Upon plugging it in, you should hear it whir into life and hold position. 
   - Repeat for all 8 motors. 

> [!TIP]
> 99% of the time, if your motor is moving in the wrong direction, crashing, or being sporadic, the motor is plugged into the wrong slot. Check your wiring!

## Attaching Hip & Leg Joints

Now we attach the joints while the motors are turned on and holding their "Stand" position.

1. **Hip Joints:** Select the matching hip joint for your motor. While in "Stand" mode, push the hip joint onto the motor shaft at a 45-degree angle. 
2. **Test Angles:** Tap "Rest" in the portal. The hip joint should move perfectly parallel to the body. Tap "Stand" again, and it should go back to 45°. Alternate this to ensure it's placed correctly.
3. **Fasten Hip:** If it looks good, fasten the hip joint to the motor using an M2.5 machine screw through the main hole into the motor shaft. Gently tighten (don't over-torque against the motor as this may cause a brownout).
4. **Legs:** Repeat the same process with the leg joints. Check against "Rest" and "Stand", ensure nothing collides, and then affix using screws.

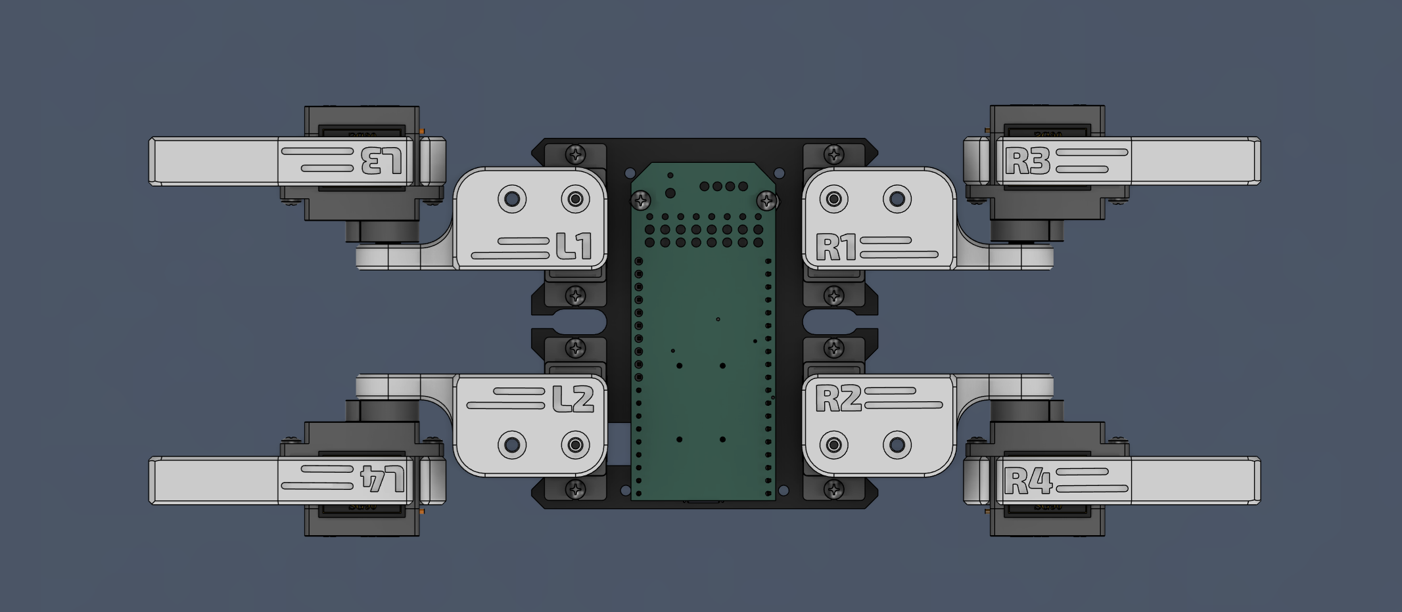
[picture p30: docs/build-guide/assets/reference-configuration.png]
reference-configuration


## Final Wiring and Top Cover

Now to clean up the robot and secure everything. 

1. **Battery Connections:** Insert the battery wires into the screw terminal on the board and use a flathead screwdriver to tighten them securely.
2. **Wire Routing:** Flip the robot over. There are channels for all the wires on the underside. Securely press all of the wires into these channels.
3. **Bundling:** Separate the wires gently into two groups (left and right). Wrap a zip tie around each bundle, fold it once, and tighten the zip tie to create a tight bundle. This helps the top cover fit seamlessly. 

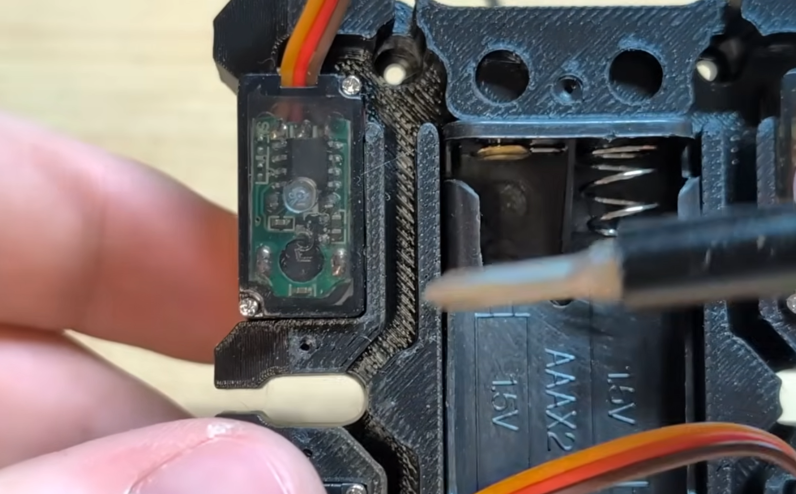
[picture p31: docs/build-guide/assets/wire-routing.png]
wire-routing


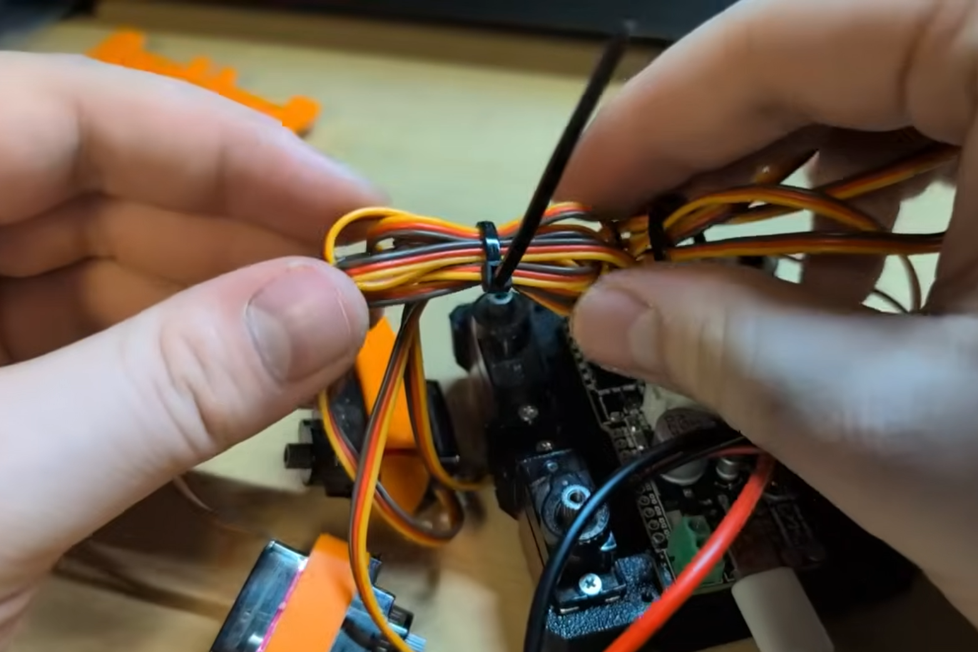
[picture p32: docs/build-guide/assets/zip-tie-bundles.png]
zip-tie-bundles


4. **Testing the Switch:** Make sure the batteries are charged and insert them. Flip the switch and check if the Wi-Fi network appears or if the display lights up. If things aren't working, double-check connections.

> [!NOTE]
> **V2 Board Owners:** If you are using the V2 Distro board from a kit, there are instabilities with the battery system that prevent reliable battery usage. You must run your Sesame via USB-C (fast charger / laptop charger) for now. A free V3 Distro board will be provided to pre-order kit buyers!

5. **Top Cover:** Gently pack all the bundles in and slowly press the top cover down onto the electronic components. Be very gentle to avoid shorting or disconnecting anything.
6. **Securing Top Cover:** Hold the whole robot together and insert the M2 self-threading screws into the bottom of the frame where they thread securely into the mounting holes for the top cover.

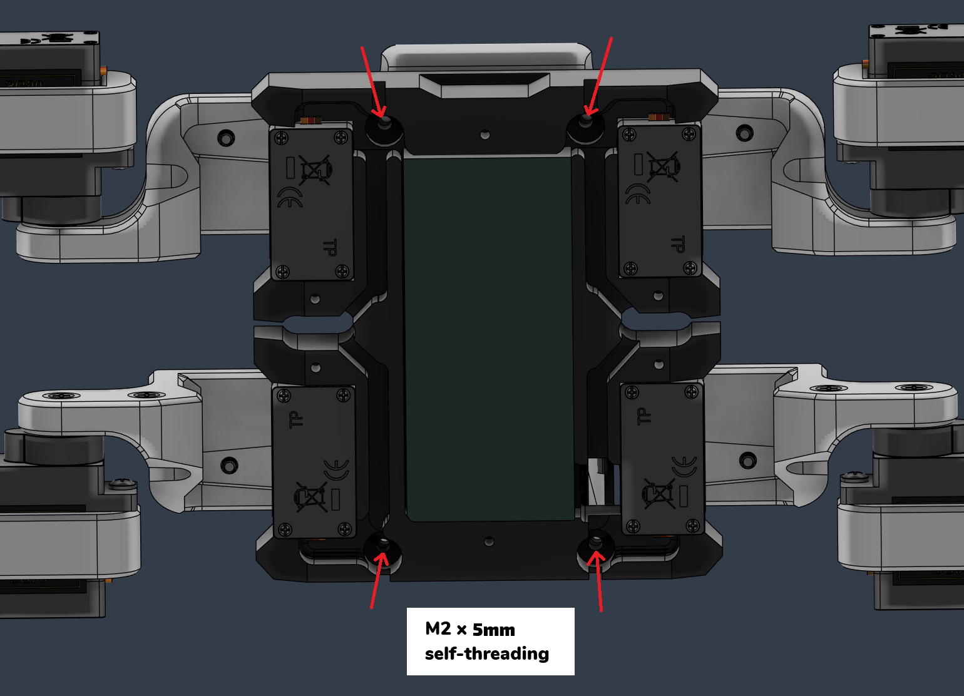
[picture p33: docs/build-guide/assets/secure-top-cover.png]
secure-top-cover


## Bottom Cover & Final Checks

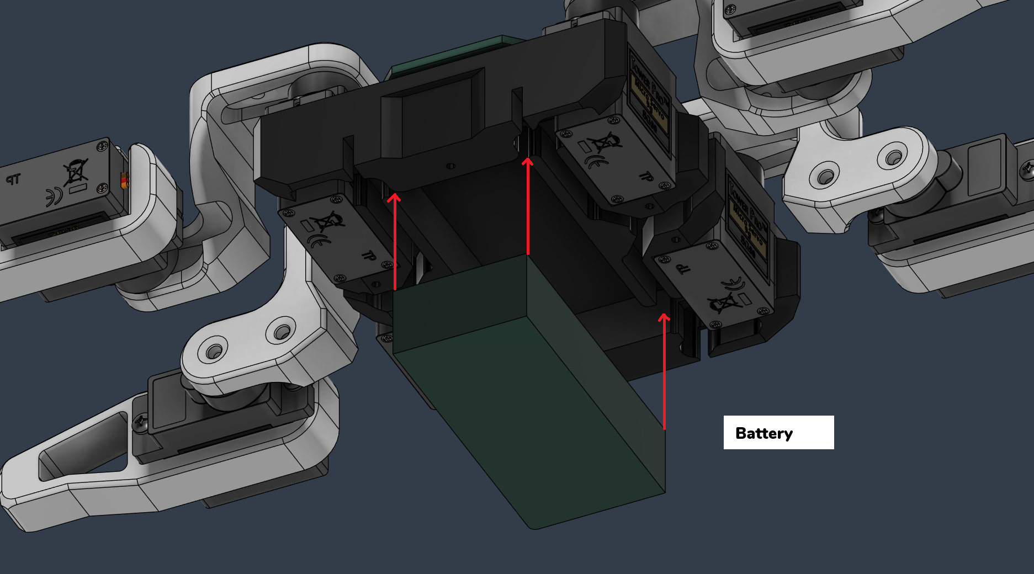
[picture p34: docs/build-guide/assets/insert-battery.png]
insert-battery


1. Set the bottom cover in place, checking that no wires are trapped. Use the remaining two self-threading screws into the bottom to secure it. 

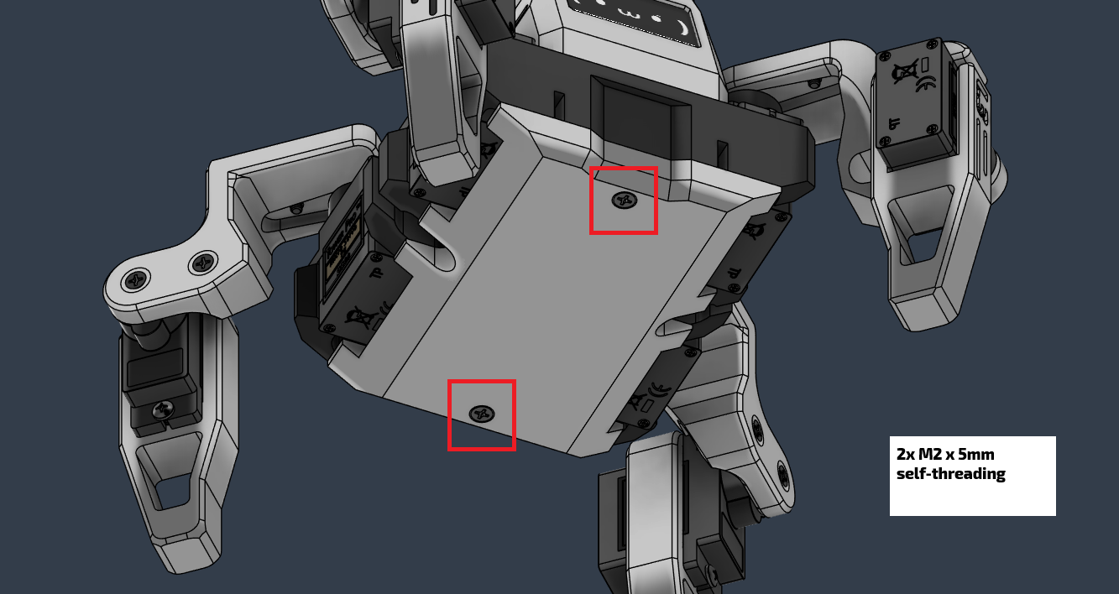
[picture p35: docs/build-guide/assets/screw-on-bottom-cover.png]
screw-on-bottom-cover


2. You can apply the included sticky pads to the feet if you like!

**Phase 4 checklist**
- [ ] Motors mounted and screwed in on hip and leg joints.
- [ ] Harness routed into channels, zip-tied without pinch points.
- [ ] Top and bottom covers installed.

> [!TIP]
> A common issue on battery power (if you upgrade) is that your Sesame robot will crash on movement. Setting the motor current delay higher in the settings may help, but upgrading to a Lithium Polymer (LiPo) cell often solves it for advanced users! 

Great job! The hardware is complete.

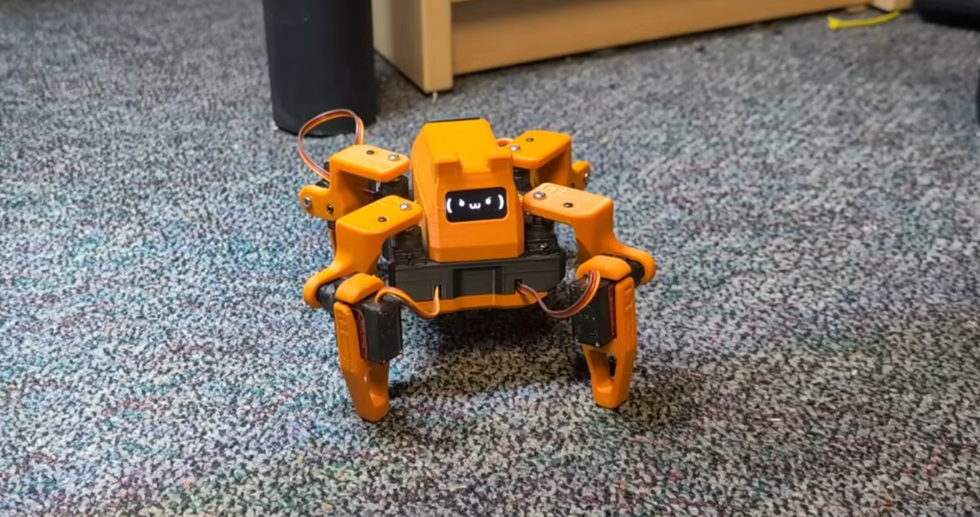
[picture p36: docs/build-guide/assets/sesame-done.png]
sesame-done


## Final Checks and Flashing the Firmware

Now we just need to do a few checks to make sure everything is working and we can flash the firmware onto the microcontroller.

**Sanity checks**
1. Toggle the power switch (if you installed a battery) and confirm it fully disconnects the pack.
2. Confirm the USB-C port is accessible for future firmware updates.
3. Inspect the OLED wiring one last time to ensure SDA/SCL aren’t swapped.

**Flash production firmware (For DIY / S2 Mini / Distro V1)**
If you are using the V2 Build kit board, you can skip this step! It is pre-flashed.
1. Choose the code variant from the firmware folder. Customize pin definitions if you're using a different ESP32.
2. Use Arduino IDE to flash the full firmware bundle (motors + faces). Detailed notes live in [firmware/README.md](../../firmware/README.md).
3. Connect to Sesame’s Wi-Fi AP, load the control page, and trigger a pose to verify everything moves as expected.

That’s it. You’ve built Sesame! From here you can design new poses in [Sesame Studio](../../software/sesame-studio/README.md) or tweak the hardware per [hardware/README.md](../../hardware/README.md), or whatever you want!

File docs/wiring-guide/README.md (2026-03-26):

# Wiring Guide

Complete wiring guides for the Sesame Robot.

---

## Choosing a Wiring Approach

The project supports multiple wiring strategies that suit different build constraints:

- **Lolin S2 Mini / hand wiring (RECOMMENDED FOR DIY BUILDS):** Uses a Lolin S2 Mini, loose headers, and point-to-point wiring. It is the lowest-cost option, easy to source, supports USB-C PD for tethered power, but demands patience to keep the harness tidy and leaves less room for mistakes. **Critical: Use 30AWG wire for data lines and 22AWG for power—larger gauge wire will make assembly nearly impossible.**
- **Sesame Distro Board V2 (INCLUDED IN BUILD KITS):** The latest custom PCB with SMD components, supports both USB-C PD and battery power. Pre-flashed and included with all Sesame Build Kits. Advanced to hand-solder; professional assembly recommended if ordering separately.
- **Sesame Distro Board V1 / ESP32-DevKitC-32E (LEGACY):** Uses the custom Distro Board V1 PCB stacked on an ESP32-DevKitC-32E. Now phased out but still supported. V1 has known limitations and cannot run on tethered USB-C power (battery + buck converter required).

Pick the approach that matches your component availability and comfort with managing wire bundles; the remainder of this guide dives into both workflows.

## How to wire the Lolin S2 Mini / Hand Wiring

The Lolin S2 Mini method is a traditional protoboard build. Consult the S2 Mini wiring diagram below while reading this section; it captures every motor, sensor, OLED, and button lead even if the photos only show a subset of the connections. Expect a high connection count, so plan wire lengths and colors before soldering to avoid confusion later.

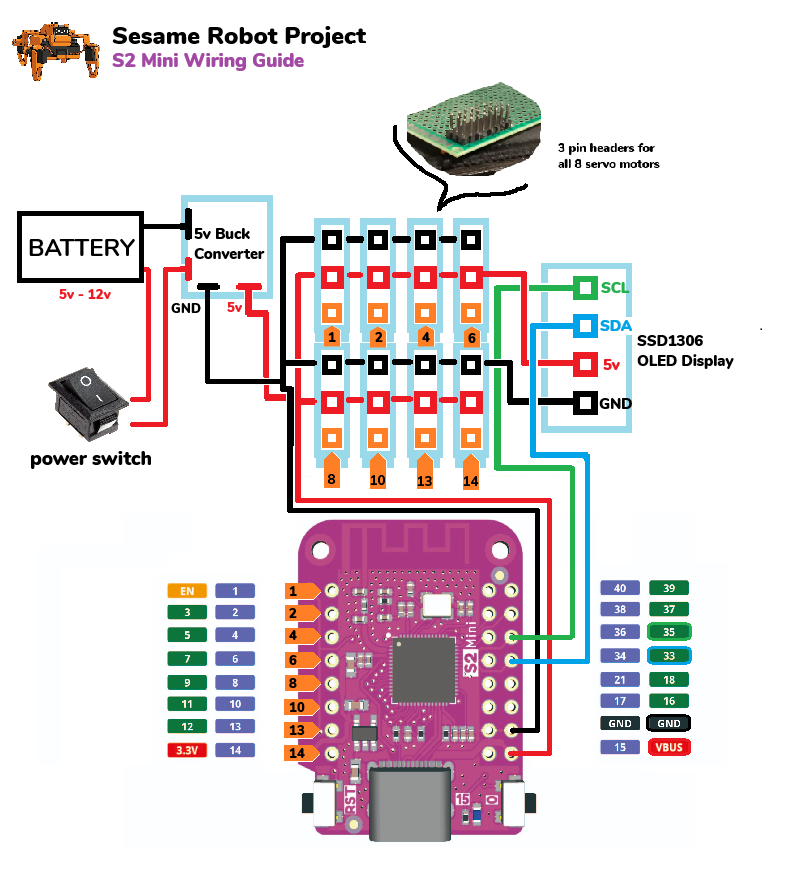
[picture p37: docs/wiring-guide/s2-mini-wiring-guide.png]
S2 Mini wiring diagram


### Prep

1. **Secure and tin** all of the connections on the board before starting
2. To connect all the 3-pin headers together and to the board, first attach them to a small section of protoboard

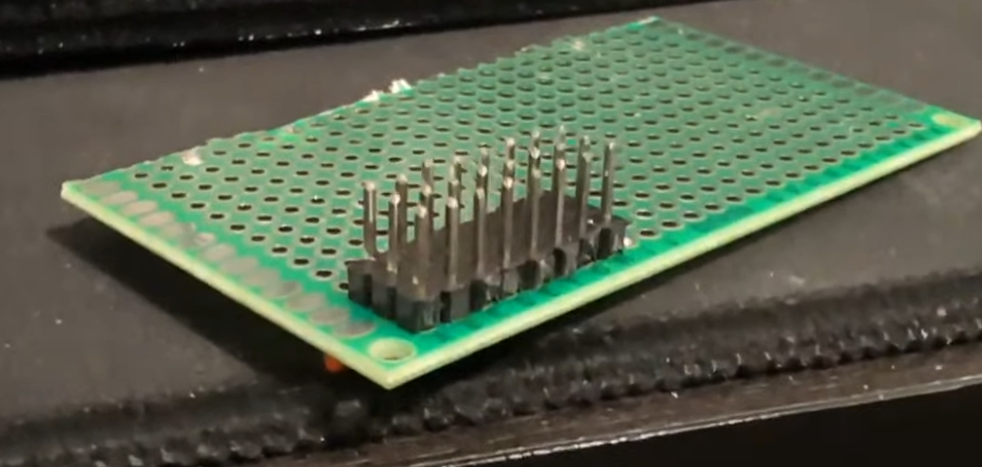
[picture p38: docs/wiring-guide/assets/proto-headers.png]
proto-headers


### Building Power and Ground Rails

1. Solder one wire to one end of the pins, then guide it along and remove the insulation
2. Solder this exposed wire to every middle pin (this creates the **5V rail**)
3. Do the same for the ground lane (this creates the **ground rail**)

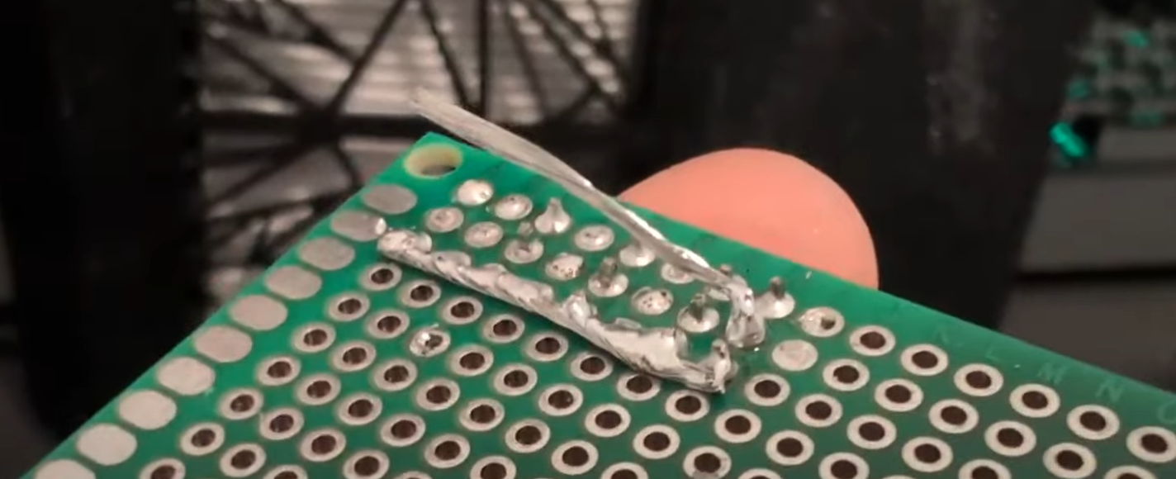
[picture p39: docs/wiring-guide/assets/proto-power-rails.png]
proto-power-rails


### Data Lines

You can now cut eight equal-length wires for data connections.

**Wire Recommendations:**
- **Data lines:** 30AWG silicone wire
- **Power and ground:** 22AWG silicone wire
- **Important:** Things will get super cluttered if you use large gauge wire

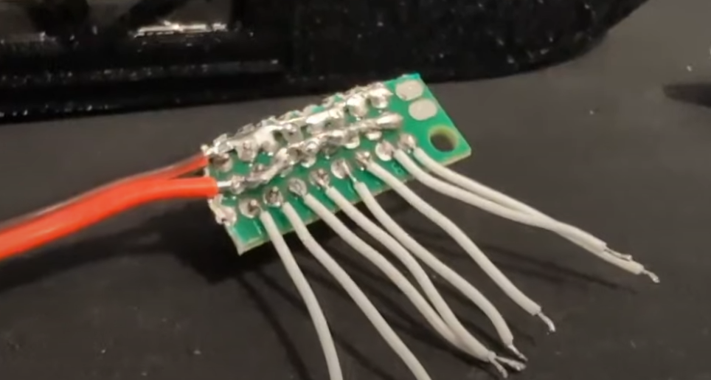
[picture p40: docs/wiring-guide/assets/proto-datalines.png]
proto-data-lines


Alongside the eight motor data leads, the diagram also calls out the OLED connections that branch from the microcontroller.

### Packing Electronics

When packing electronics into the frame, it's difficult with the hand wiring setup because there are a lot of stray wires. My advice is to work slowly and methodically:

1. Group wires with similar destinations
2. Use zip ties and heat shrink tubing to make them as compact as possible
3. Consider connecting the power switch after finishing most other wiring, since it's attached to the top cover

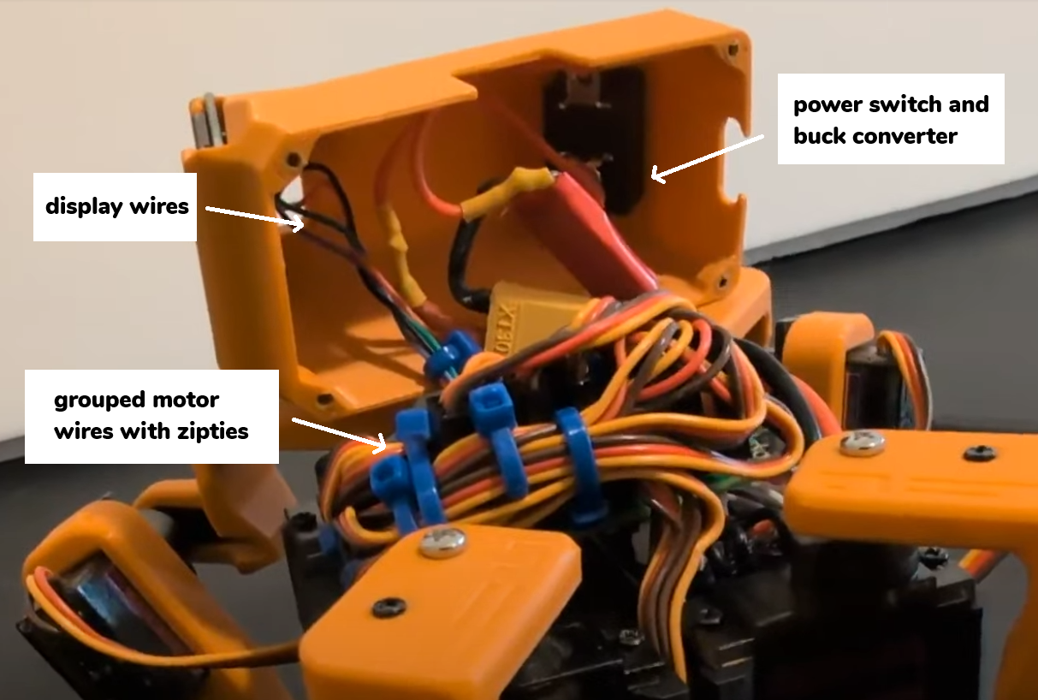
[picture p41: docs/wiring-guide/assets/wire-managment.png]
wire-managment


### Safety and Testing

> [!CAUTION]
> Do not solder and de-solder connections with power connected!

**Before powering on:**
- Double check your power and ground lines before turning the robot on
- Make sure to cover any exposed wires as they can touch the pin headers and fry the ESP32 (especially when cramming the cover on)

> [!TIP]
> To make fishing out the wires for the OLED display easier, you can temporarily twist them together into a group and then guide them through the opening in the top cover.

---

## How to wire the Sesame Distro Board V1 / ESP32-DevKitC-32E

### Overview

> [!CAUTION]  
> UPDATE 1/20/26: Upon further testing, the Sesame distro board V1 will work, but it has a few issues that make it a little harder to assemble and will not run on teathered power (eg. USB C). Until V2 is released, I recommend using the S2 Mini / Hand Wiring approach. If you ordered a distro board V1, it will still be supported with wiring guides and firmware for the foreseeable future <3.

This option provides a cleaner, more organized wiring solution.
Consult the distro-board wiring diagram below for exact connection locations.

> [!IMPORTANT]
> **ESP32 Pin Header Requirement:** The distro board V1 stacks on top of the ESP32-DevKitC-32E, so you need an ESP32 board **without pre-soldered pin headers**. If your board came with headers already soldered on the top, you will need to desolder all of the headers and flip them to the bottom side of the ESP32 board so the distro board can mount on top.

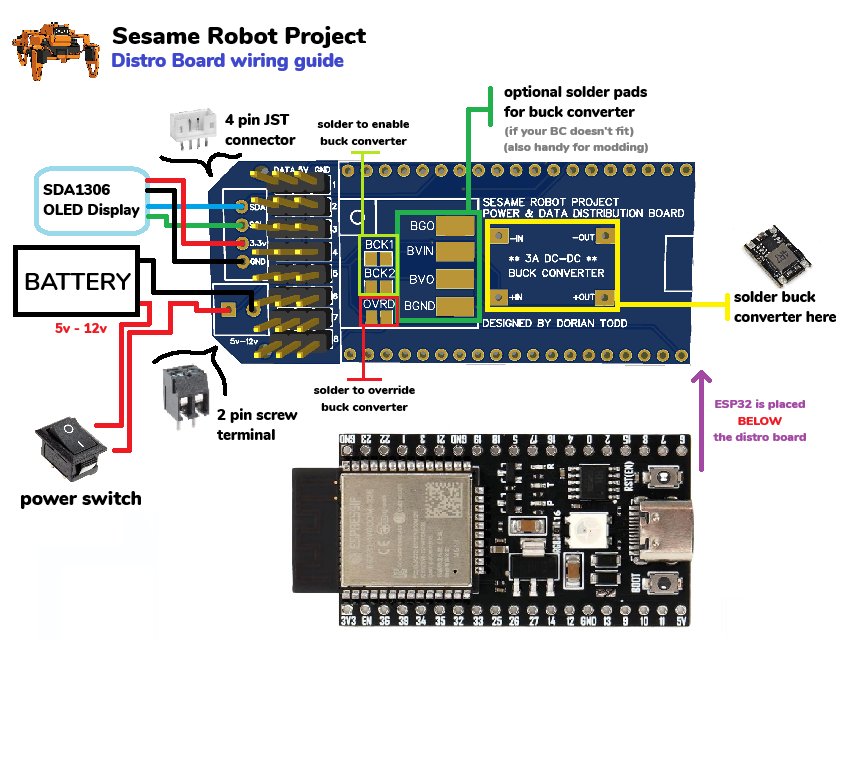
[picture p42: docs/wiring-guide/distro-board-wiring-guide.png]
distro-board wiring diagram


### Component Installation

**Optional components** (you can solder directly to pads instead):
- 4-pin JST connector
- 2-pin screw terminal

**Pin header installation tip:** If you're having difficulties keeping the pin headers in place to solder, try placing them in a protoboard first, then transferring them over.

### Buck Converter Setup

A buck converter takes any voltage (5V-12V) and drops it to a stable 5V for the motors and ESP32.

**If using a battery:**
1. Make sure to solder the buck converter enable pads
2. The buck converter is **required** for battery operation
3. 2× 10440 Li-ion cells in a 2× AAA holder (2S, ~7.4 V nominal) work well with the buck and fit the chassis battery slot

**Alternative power options:**
- If you're using a benchtop supply or have another regulated 5V source
- You can override the buck converter and take voltage directly from the screw terminal by soldering the override pads

### Battery Connection
> [!CAUTION]
> If your battery has an XT30 or JST RCY connector, don't cut it off and wire the battery directly to the distro board! This is unsafe and means you can't charge your battery anymore.

**Proper method:**
1. Get a female XT30 or JST RCY connector (matching your battery)
2. Wire it to two wires that lead to the power terminal
3. This allows you to safely connect and disconnect the battery

**Note on 2× AAA holders with 10440 Li-ion cells:**
- Treat this as a 2S Li-ion pack; wire the holder leads through the switch and buck converter.
- **Always remove the 10440 cells from the holder and recharge them separately using a proper Li-ion charger.** Most AAA holders do not support safe Li-ion charging and attempting to charge in-holder can be dangerous.

### Sourcing the Distro Board

The Sesame Distro Board V1 is a custom PCB designed specifically for this project. It mounts on top of a ESP32-DevKitC-32E.

More information is avalible in the [PCB](../../hardware/pcb/README.md) section of the documentation.

---

## General Wiring Tips

- Work slowly and methodically
- Test connections before applying power
- Keep wire runs as short and neat as possible
- Label wires if helpful for troubleshooting
- Take photos during assembly for reference

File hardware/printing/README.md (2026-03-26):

# 3D Printing Guide

Sesame is designed to be printed in **PLA**. Most parts print without supports, but the top cover needs supports in targeted areas. Below is a quick reference for each component:

Note: There are 3 different top cover styles currently available. **Enclosed v91 is recommended** as it's the most modern design with magnetic hat mounts, covered display wires, and multicolor detail support. See [Top Covers](stl/top-covers/) for details on all styles.

## Recommended Settings
* **Material:** PLA / PLA+
* **Infill:** 8-10%
* **Wall Loops:** 2
* **Infill Pattern:** Honeycomb

## 3D Printed Components Support Guide

| Component | Supports Required | STL Link |
|---|---|---|
| Joint R1 | No | [R1-v117.stl](stl/R1-v117.stl) |
| Joint R2 | No | [R2-v117.stl](stl/R2-v117.stl) |
| Joint R3 | No | [R3-v117.stl](stl/R3-v117.stl) |
| Joint R4 | No | [R4-v117.stl](stl/R4-v117.stl) |
| Joint L1 | No | [L1-v117.stl](stl/L1-v117.stl) |
| Joint L2 | No | [L2-v117.stl](stl/L2-v117.stl) |
| Joint L3 | No | [L3-v117.stl](stl/L3-v117.stl) |
| Joint L4 | No | [L4-v117.stl](stl/L4-v117.stl) |
| Internal Frame  | No | [Internal-Frame-v117.stl](stl/Internal-Frame-v117.stl) |
| Bottom Cover | No | [Bottom-Cover-v117.stl](stl/Bottom-Cover-v117.stl) |
| Top Cover | Yes | [Top Covers](stl/top-covers/) |

### Top Cover Settings (Original Style)

Brim: Outer brim only
Support type: Normal (Manual)

Manual support locations:

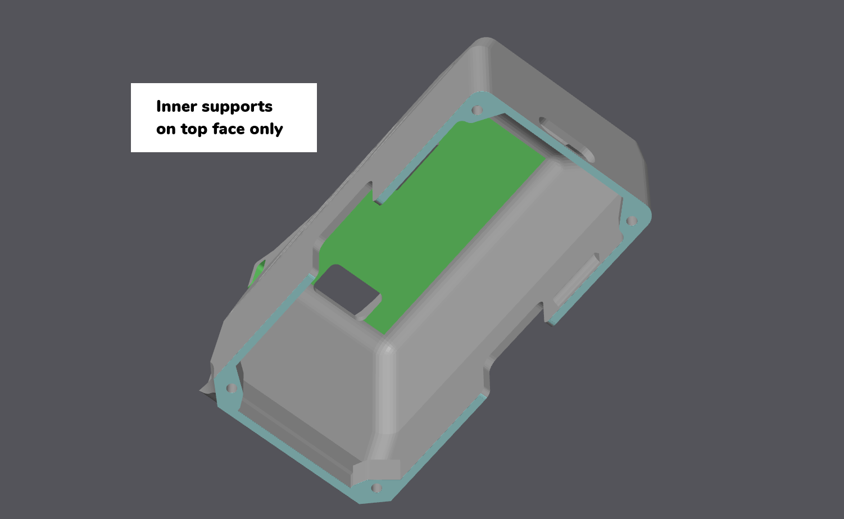
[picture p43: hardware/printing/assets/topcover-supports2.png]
topcover-supports2


This is what the part should look like sliced:

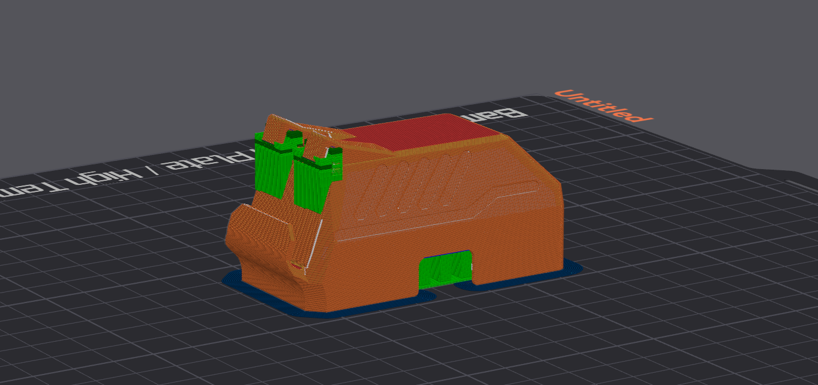
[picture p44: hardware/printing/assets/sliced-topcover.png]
sliced-topcover


### Recommended Print Orientation for Joints:

Using the auto orientate tool will place these the correct way. 

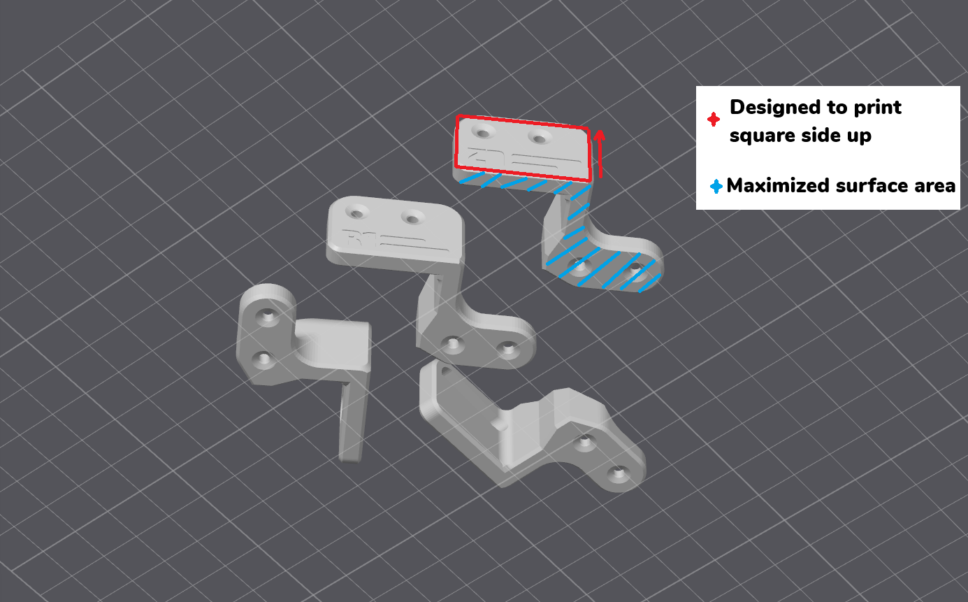
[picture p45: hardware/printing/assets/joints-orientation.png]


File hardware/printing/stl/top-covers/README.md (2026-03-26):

# Top Cover Styles

## Enclosed v100
Current modern version of sesame top cover, includes 5mm x 2mm magnet slots for hats! Front display wires are covered, supports multicolor details.

## Cat v100
Modern Version of the enclosed top cover with cat ears instead of stubby ears! Updated with all current features with magnet support for hats, and multicolor details.

## No Ears v100
Template for designing your own ears for Sesame. The areas right next to where the ears ussually go is a little thin so this version is only really meant for desiging ears onto. (Includes all previously mentioned features)

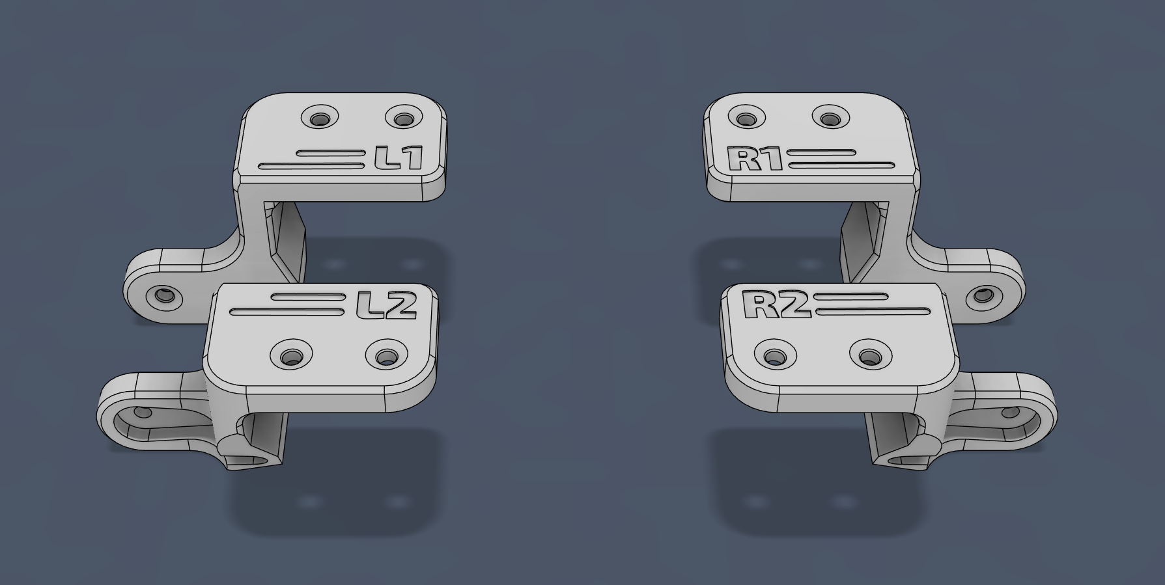
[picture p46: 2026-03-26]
docs/build-guide/assets/joints-preassem.png

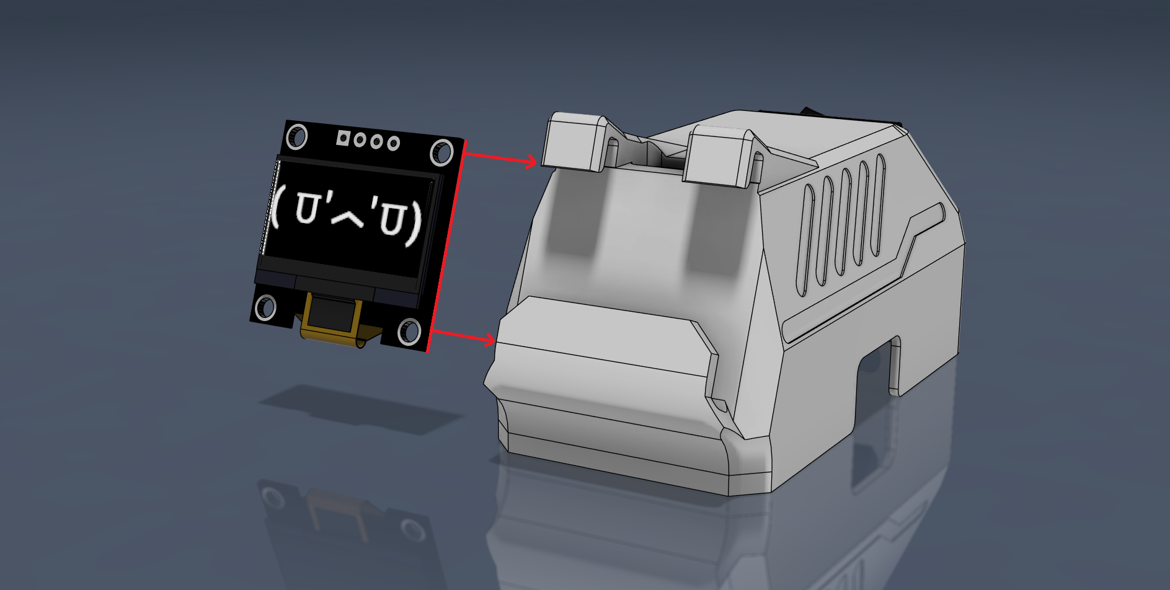
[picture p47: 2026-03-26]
docs/build-guide/assets/insert-display.png

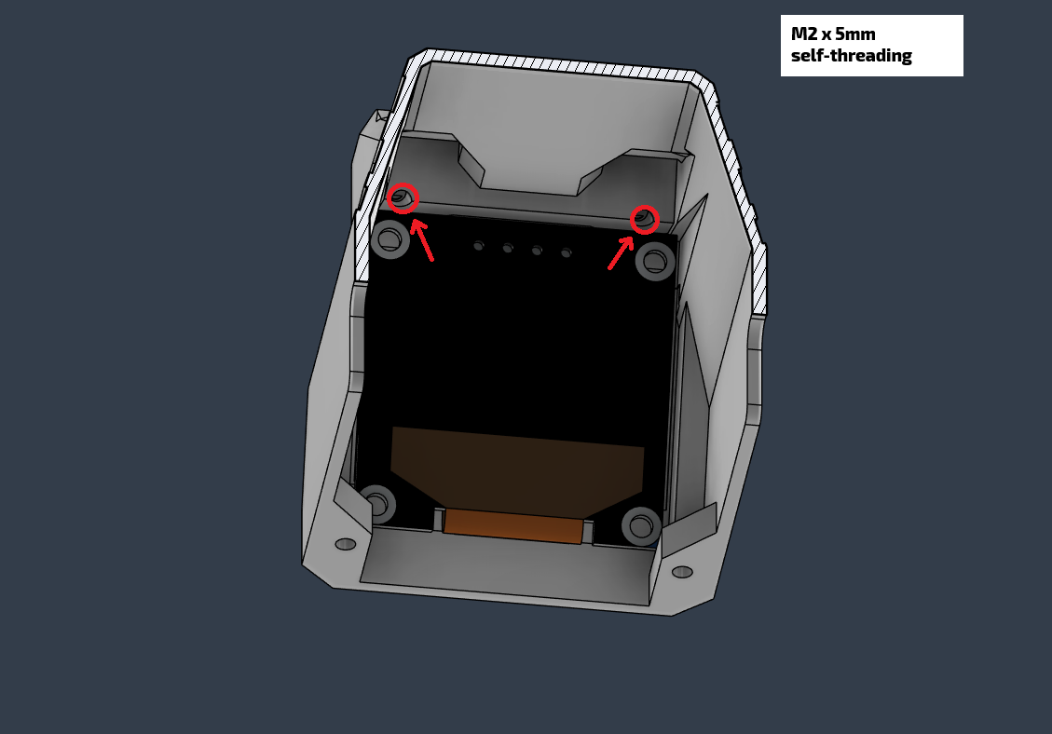
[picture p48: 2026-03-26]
docs/build-guide/assets/securing-display-enclosed.png

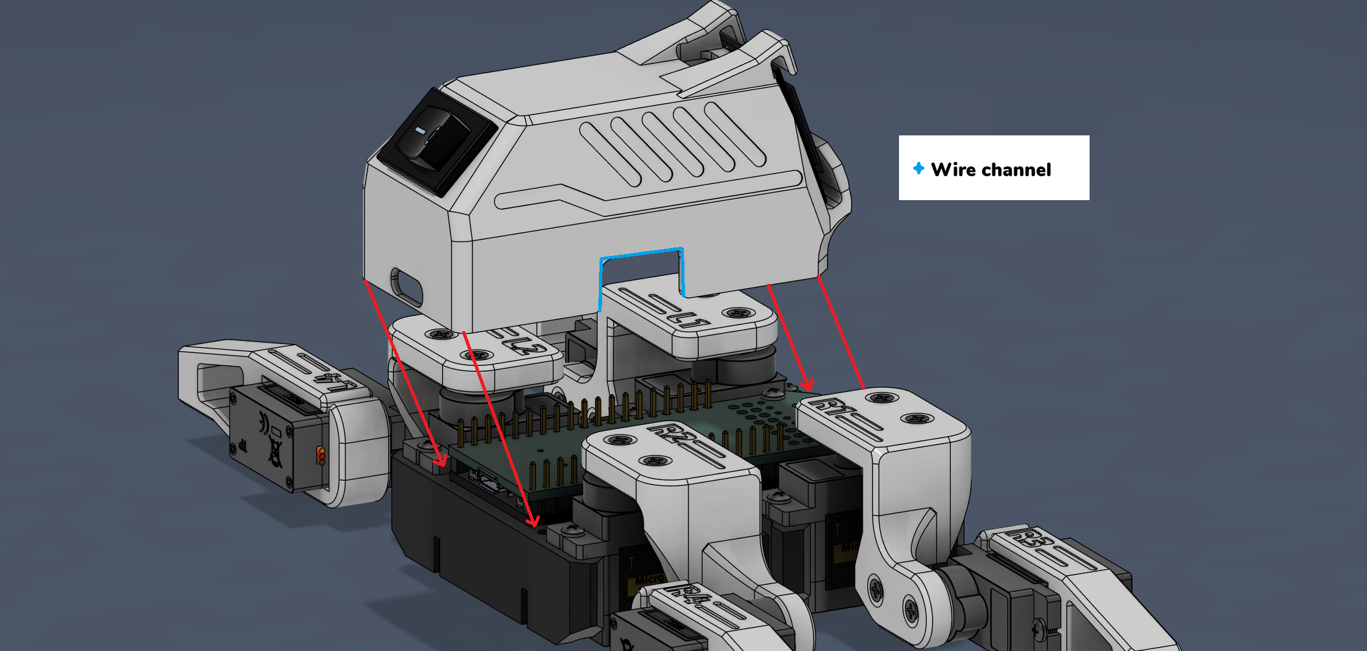
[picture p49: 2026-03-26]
docs/build-guide/assets/push-on-top-cover.png

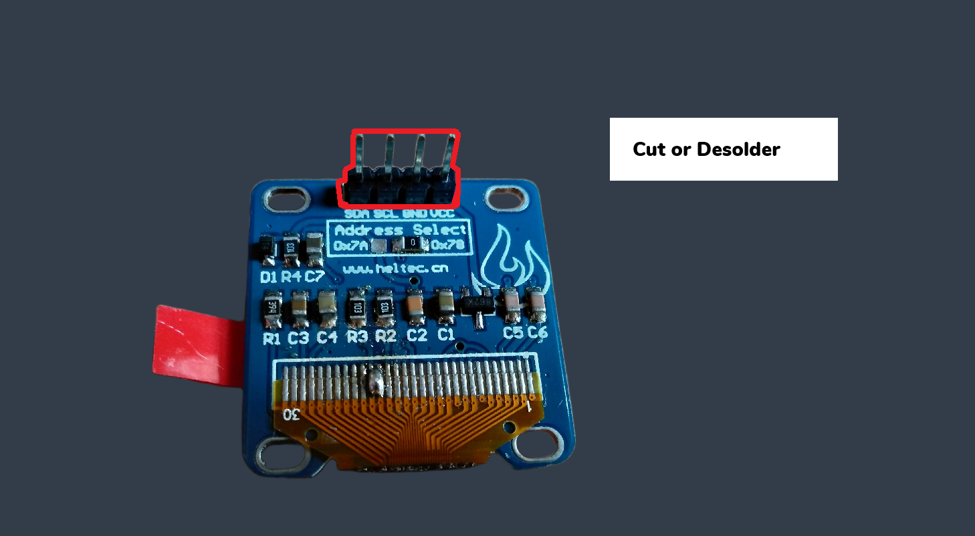
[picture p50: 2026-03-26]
docs/build-guide/assets/remove-headers.png

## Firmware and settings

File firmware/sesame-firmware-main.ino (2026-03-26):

#include <WiFi.h>
#include <WebServer.h>
#include <DNSServer.h>
#include <ESPmDNS.h>
#include <Wire.h>
#include <ESP32Servo.h>
#include <Adafruit_GFX.h>
#include <Adafruit_SSD1306.h>
#include "face-bitmaps.h"
#include "movement-sequences.h"
#include "captive-portal.h"

// --- Access Point Configuration ---
// This is the network the Robot will create
#define AP_SSID  "Sesame-Controller"
#define AP_PASS  "12345678" // Must be at least 8 characters

// --- Station Mode Configuration (Optional) ---
// Set these to connect to your home/office WiFi network
// Leave NETWORK_SSID empty to disable station mode
#define NETWORK_SSID ""  // Your WiFi network name
#define NETWORK_PASS ""  // Your WiFi password
#define ENABLE_NETWORK_MODE false  // Set to true to enable network connection attempts

#define SCREEN_WIDTH 128
#define SCREEN_HEIGHT 64
#define OLED_RESET -1
#define OLED_I2C_ADDR 0x3C

// I2C Pins for Distro Board V2
//#define I2C_SDA 8
//#define I2C_SCL 9

// I2C Pins for Distro Board
//#define I2C_SDA 21
//#define I2C_SCL 22

// I2C Pins for S2 Mini Board
#define I2C_SDA 33
#define I2C_SCL 35


// DNS Server for Captive Portal
DNSServer dnsServer;
const byte DNS_PORT = 53;

Adafruit_SSD1306 display(SCREEN_WIDTH, SCREEN_HEIGHT, &Wire, OLED_RESET);
WebServer server(80);

// Global state for animations
String currentCommand = "";
String currentFaceName = "default";
const unsigned char* const* currentFaceFrames = nullptr;
uint8_t currentFaceFrameCount = 0;
uint8_t currentFaceFrameIndex = 0;
unsigned long lastFaceFrameMs = 0;
int faceFps = 8;
FaceAnimMode currentFaceMode = FACE_ANIM_LOOP;
int8_t faceFrameDirection = 1;
bool faceAnimFinished = false;
int currentFaceFps = 0;
bool idleActive = false;
bool idleBlinkActive = false;
unsigned long nextIdleBlinkMs = 0;
uint8_t idleBlinkRepeatsLeft = 0;

// WiFi Info Scrolling
unsigned long lastInputTime = 0;
bool firstInputReceived = false;
bool showingWifiInfo = false;
int wifiScrollPos = 0;
unsigned long lastWifiScrollMs = 0;
String wifiInfoText = "";

// Network Mode
bool networkConnected = false;
IPAddress networkIP;
String deviceHostname = "sesame-robot";

// Servo Pins for Distro Board
// ======================================================================
// Pin numbers are coorisponding to the ESP32 GPIO pins and may differ based on which board you use.
// If you are using a different board, please adjust the servoPins array accordingly.
// ======================================================================
Servo servos[8];
// Sesame Distro Board V2 Pinout
//const int servoPins[8] = {4, 5, 6, 7, 15, 16, 17, 18};

// Sesame Distro Board Pinout
//const int servoPins[8] = {15, 2, 23, 19, 4, 16, 17, 18};

// Lolin S2 Mini Pinout
const int servoPins[8] = {1, 2, 4, 6, 8, 10, 13, 14};

// Subtrim values for each servo (offset in degrees)
int8_t servoSubtrim[8] = {0, 0, 0, 0, 0, 0, 0, 0};


// Animation constants
int frameDelay = 100;
int walkCycles = 10;
int motorCurrentDelay = 20; // ms delay between motor movements to prevent over-current

struct FaceEntry {
  const char* name;
  const unsigned char* const* frames;
  uint8_t maxFrames;
};

static const uint8_t MAX_FACE_FRAMES = 6;

#define MAKE_FACE_FRAMES(name) \
  const unsigned char* const face_##name##_frames[] = { \
    epd_bitmap_##name, epd_bitmap_##name##_1, epd_bitmap_##name##_2, \
    epd_bitmap_##name##_3, epd_bitmap_##name##_4, epd_bitmap_##name##_5 \
  };

#define X(name) MAKE_FACE_FRAMES(name)
FACE_LIST
#undef X
#undef MAKE_FACE_FRAMES

const FaceEntry faceEntries[] = {
#define X(name) { #name, face_##name##_frames, MAX_FACE_FRAMES },
  FACE_LIST
#undef X
  { "default", face_defualt_frames, MAX_FACE_FRAMES }
};

struct FaceFpsEntry {
  const char* name;
  uint8_t fps;
};

const FaceFpsEntry faceFpsEntries[] = {
  { "walk", 1 },
  { "rest", 1 },
  { "swim", 1 },
  { "dance", 1 },
  { "wave", 1 },
  { "point", 5 },
  { "stand", 1 },
  { "cute", 1 },
  { "pushup", 1 },
  { "freaky", 1 },
  { "bow", 1 },
  { "worm", 1 },
  { "shake", 1 },
  { "shrug", 1 },
  { "dead", 2 },
  { "crab", 1 },
  { "idle", 1 },
  { "idle_blink", 7 },
  { "default", 1 },
  // Conversational faces (manually controlled by Python - no auto-animation)
  { "happy", 1 },
  { "talk_happy", 1 },
  { "sad", 1 },
  { "talk_sad", 1 },
  { "angry", 1 },
  { "talk_angry", 1 },
  { "surprised", 1 },
  { "talk_surprised", 1 },
  { "sleepy", 1 },
  { "talk_sleepy", 1 },
  { "love", 1 },
  { "talk_love", 1 },
  { "excited", 1 },
  { "talk_excited", 1 },
  { "confused", 1 },
  { "talk_confused", 1 },
  { "thinking", 1 },
  { "talk_thinking", 1 },
};


// Prototypes
void setServoAngle(uint8_t channel, int angle);
void updateFaceBitmap(const unsigned char* bitmap);
void setFace(const String& faceName);
void setFaceMode(FaceAnimMode mode);
void setFaceWithMode(const String& faceName, FaceAnimMode mode);
void updateAnimatedFace();
void delayWithFace(unsigned long ms);
void enterIdle();
void exitIdle();
void updateIdleBlink();
int getFaceFpsForName(const String& faceName);
bool pressingCheck(String cmd, int ms);
void handleGetSettings();
void handleSetSettings();
void handleGetStatus();
void handleApiCommand();
void updateWifiInfoScroll();
void recordInput();

void handleRoot() {
  server.send(200, "text/html", index_html);
}

void handleCommandWeb() {
  // We send 200 OK immediately so the web browser doesn't hang waiting for animation to finish
  if (server.hasArg("pose")) {
    currentCommand = server.arg("pose");
    recordInput();
    exitIdle();
    server.send(200, "text/plain", "OK"); 
  } 
  else if (server.hasArg("go")) {
    currentCommand = server.arg("go");
    recordInput();
    exitIdle();
    server.send(200, "text/plain", "OK");
  } 
  else if (server.hasArg("stop")) {
    currentCommand = "";
    recordInput();
    server.send(200, "text/plain", "OK");
  }
  else if (server.hasArg("motor") && server.hasArg("value")) {
    int motorNum = server.arg("motor").toInt();
    int servoIdx = servoNameToIndex(server.arg("motor"));
    int angle = server.arg("value").toInt();
    if (motorNum >= 1 && motorNum <= 8 && angle >= 0 && angle <= 180) {
      setServoAngle(motorNum - 1, angle); // Convert 1-based to 0-based index
      recordInput();
      server.send(200, "text/plain", "OK");
    } else if (servoIdx != -1 && angle >= 0 && angle <= 180) {
      setServoAngle(servoIdx, angle);
      recordInput();
      server.send(200, "text/plain", "OK");
    } else {
      server.send(400, "text/plain", "Invalid motor or angle");
    }
  }
  else {
    server.send(400, "text/plain", "Bad Args");
  }
}

void handleGetSettings() {
  String json = "{";
  json += "\"frameDelay\":" + String(frameDelay) + ",";
  json += "\"walkCycles\":" + String(walkCycles) + ",";
  json += "\"motorCurrentDelay\":" + String(motorCurrentDelay) + ",";
  json += "\"faceFps\":" + String(faceFps);
  json += "}";
  server.send(200, "application/json", json);
}

void handleSetSettings() {
  if (server.hasArg("frameDelay")) frameDelay = server.arg("frameDelay").toInt();
  if (server.hasArg("walkCycles")) walkCycles = server.arg("walkCycles").toInt();
  if (server.hasArg("motorCurrentDelay")) motorCurrentDelay = server.arg("motorCurrentDelay").toInt();
  if (server.hasArg("faceFps")) faceFps = (int)max(1L, server.arg("faceFps").toInt());
  server.send(200, "text/plain", "OK");
}

// API endpoint for network clients to get robot status
void handleGetStatus() {
  String json = "{";
  json += "\"currentCommand\":\"" + currentCommand + "\",";
  json += "\"currentFace\":\"" + currentFaceName + "\",";
  json += "\"networkConnected\":" + String(networkConnected ? "true" : "false") + ",";
  json += "\"apIP\":\"" + WiFi.softAPIP().toString() + "\"";
  if (networkConnected) {
    json += ",\"networkIP\":\"" + networkIP.toString() + "\"";
  }
  json += "}";
  server.send(200, "application/json", json);
}

// API endpoint for network clients to send commands (JSON-based)
void handleApiCommand() {
  if (server.method() != HTTP_POST) {
    server.send(405, "application/json", "{\"error\":\"Method not allowed\"}");
    return;
  }
  
  String body = server.arg("plain");
  
  Serial.println("API Command received:");
  Serial.println(body);
  
  // Check for face-only command (no movement)
  int faceOnlyStart = body.indexOf("\"face\":\"");
  if (faceOnlyStart == -1) {
    faceOnlyStart = body.indexOf("\"face\": \"");
  }
  
  // If we have a face but no command field, it's face-only
  bool faceOnly = (faceOnlyStart > 0 && body.indexOf("\"command\":") == -1 && body.indexOf("\"command\": ") == -1);
  
  String command = "";
  String face = "";
  
  // Parse face
  if (faceOnlyStart > 0) {
    faceOnlyStart = body.indexOf("\"", faceOnlyStart + 6) + 1;
    int faceEnd = body.indexOf("\"", faceOnlyStart);
    if (faceEnd > faceOnlyStart) {
      face = body.substring(faceOnlyStart, faceEnd);
      Serial.print("Parsed face: ");
      Serial.println(face);
    }
  }
  
  // Parse command (if not face-only)
  if (!faceOnly) {
    int cmdStart = body.indexOf("\"command\":\"");
    if (cmdStart == -1) {
      cmdStart = body.indexOf("\"command\": \"");
    }
    
    if (cmdStart == -1) {
      Serial.println("Error: command field not found");
      server.send(400, "application/json", "{\"error\":\"Missing command field\"}");
      return;
    }
    
    cmdStart = body.indexOf("\"", cmdStart + 10) + 1;
    int cmdEnd = body.indexOf("\"", cmdStart);
    
    if (cmdEnd <= cmdStart) {
      Serial.println("Error: invalid command format");
      server.send(400, "application/json", "{\"error\":\"Invalid command format\"}");
      return;
    }
    
    command = body.substring(cmdStart, cmdEnd);
    Serial.print("Parsed command: ");
    Serial.println(command);
  }
  
  // Set face if provided
  if (face.length() > 0) {
    setFace(face);
  }
  
  // If face-only, just acknowledge
  if (faceOnly) {
    recordInput();
    server.send(200, "application/json", "{\"status\":\"ok\",\"message\":\"Face updated\"}");
    return;
  }
  
  // Execute command
  if (command == "stop") {
    currentCommand = "";
    recordInput();
    server.send(200, "application/json", "{\"status\":\"ok\",\"message\":\"Command stopped\"}");
  } else {
    currentCommand = command;
    recordInput();
    exitIdle();
    server.send(200, "application/json", "{\"status\":\"ok\",\"message\":\"Command executed\"}");
  }
}

void setup() {
  Serial.begin(115200);
  randomSeed(micros());
  
  // I2C Init for ESP32
  Wire.begin(I2C_SDA, I2C_SCL);

  // OLED Init
  if (!display.begin(SSD1306_SWITCHCAPVCC, OLED_I2C_ADDR)) {
    Serial.println(F("SSD1306 allocation failed."));
    while (1);
  }
  
  display.clearDisplay();
  display.setTextColor(SSD1306_WHITE);
  display.setTextSize(1);
  display.setCursor(0,0);
  display.println(F("Setting up WiFi..."));
  display.display();

  // --- WIFI CONFIGURATION ---
  // Try to connect to network first if configured
  if (ENABLE_NETWORK_MODE && String(NETWORK_SSID).length() > 0) {
    Serial.println("Attempting to connect to network: " + String(NETWORK_SSID));
    WiFi.mode(WIFI_AP_STA); // Enable both AP and Station modes
    WiFi.setHostname(deviceHostname.c_str());
    WiFi.begin(NETWORK_SSID, NETWORK_PASS);
    
    // Wait up to 10 seconds for connection
    int attempts = 0;
    while (WiFi.status() != WL_CONNECTED && attempts < 20) {
      delay(500);
      Serial.print(".");
      attempts++;
    }
    
    if (WiFi.status() == WL_CONNECTED) {
      networkConnected = true;
      networkIP = WiFi.localIP();
      Serial.println();
      Serial.print("Connected to network! IP: ");
      Serial.println(networkIP);
    } else {
      Serial.println();
      Serial.println("Failed to connect to network. Running in AP-only mode.");
      WiFi.mode(WIFI_AP); // Fall back to AP-only
    }
  } else {
    WiFi.mode(WIFI_AP);
    Serial.println("Network mode disabled. Running in AP-only mode.");
  }
  
  // --- ACCESS POINT CONFIGURATION ---
  WiFi.softAP(AP_SSID, AP_PASS);
  IPAddress myIP = WiFi.softAPIP();
  
  Serial.print("AP Created. IP: ");
  Serial.println(myIP);

  // Build WiFi info text for scrolling
  if (networkConnected) {
    wifiInfoText = "AP: " + String(AP_SSID) + " (" + myIP.toString() + ")  |  Network: " + String(NETWORK_SSID) + " (" + networkIP.toString() + ") or " + deviceHostname + ".local  |  ";
  } else {
    wifiInfoText = "Connect to WiFi: " + String(AP_SSID) + "  |  Pass: " + String(AP_PASS) + "  |  IP: " + myIP.toString() + "  |  Captive Portal will auto-open!  |  ";
  }
  
  // Initialize input tracking
  lastInputTime = millis();
  firstInputReceived = false;
  showingWifiInfo = false;

  // Start mDNS responder for local network discovery
  if (MDNS.begin(deviceHostname.c_str())) {
    Serial.println("mDNS responder started");
    Serial.print("Access controller at: http://");
    Serial.print(deviceHostname);
    Serial.println(".local");
    MDNS.addService("http", "tcp", 80);
  } else {
    Serial.println("Error setting up mDNS responder!");
  }

  // Start DNS Server for Captive Portal
  // This redirects ALL domain requests to the ESP32's IP
  dnsServer.start(DNS_PORT, "*", myIP);

  // Web Server Routes
  server.on("/", handleRoot);
  server.on("/cmd", handleCommandWeb);
  server.on("/getSettings", handleGetSettings);
  server.on("/setSettings", handleSetSettings);
  
  // API endpoints for network communication
  server.on("/api/status", handleGetStatus);
  server.on("/api/command", handleApiCommand);
  
  // Catch-all route for captive portal
  // This ensures any URL redirects to the controller page
  server.onNotFound(handleRoot);
  
  server.begin();

  // PWM Init
  ESP32PWM::allocateTimer(0);
  ESP32PWM::allocateTimer(1);
  ESP32PWM::allocateTimer(2);
  ESP32PWM::allocateTimer(3);
  
  for (int i = 0; i < 8; i++) {
    servos[i].setPeriodHertz(50);
    // Map 0-180 to approx 732-2929us
    servos[i].attach(servoPins[i], 732, 2929);
  }
  delay(10);
  
  // Show rest face on startup without moving motors
  setFace("rest");
  
  Serial.println(F("HTTP server & Captive Portal started."));
}

void loop() {
  // Process DNS requests for captive portal
  dnsServer.processNextRequest();
  
  server.handleClient();
  updateAnimatedFace();
  updateIdleBlink();
  updateWifiInfoScroll();

  if (currentCommand != "") {
    String cmd = currentCommand;
    if (cmd == "forward") runWalkPose();
    else if (cmd == "backward") runWalkBackward();
    else if (cmd == "left") runTurnLeft();
    else if (cmd == "right") runTurnRight();
    else if (cmd == "rest") { runRestPose(); if (currentCommand == "rest") currentCommand = ""; }
    else if (cmd == "stand") { runStandPose(1); if (currentCommand == "stand") currentCommand = ""; }
    else if (cmd == "wave") runWavePose();
    else if (cmd == "dance") runDancePose();
    else if (cmd == "swim") runSwimPose();
    else if (cmd == "point") runPointPose();
    else if (cmd == "pushup") runPushupPose();
    else if (cmd == "bow") runBowPose();
    else if (cmd == "cute") runCutePose();
    else if (cmd == "freaky") runFreakyPose();
    else if (cmd == "worm") runWormPose();
    else if (cmd == "shake") runShakePose();
    else if (cmd == "shrug") runShrugPose();
    else if (cmd == "dead") runDeadPose();
    else if (cmd == "crab") runCrabPose();
  }
  
  // Serial CLI for debugging (can be used to diagnose servo position issues and wiring)
  if (Serial.available()) {
    static char command_buffer[32];
    static byte buffer_pos = 0;
    char c = Serial.read();
    if (c == '\n' || c == '\r') {
      if (buffer_pos > 0) {
        command_buffer[buffer_pos] = '\0';
        int motorNum, angle;
        recordInput();
        if(strcmp(command_buffer, "run walk") == 0 || strcmp(command_buffer, "rn wf") == 0) { currentCommand = "forward"; runWalkPose(); currentCommand = ""; }
        else if(strcmp(command_buffer, "rn wb") == 0) { currentCommand = "backward"; runWalkBackward(); currentCommand = ""; }
        else if(strcmp(command_buffer, "rn tl") == 0) { currentCommand = "left"; runTurnLeft(); currentCommand = ""; }
        else if(strcmp(command_buffer, "rn tr") == 0) { currentCommand = "right"; runTurnRight(); currentCommand = ""; }
        else if(strcmp(command_buffer, "run rest") == 0 || strcmp(command_buffer, "rn rs") == 0) runRestPose();
        else if(strcmp(command_buffer, "run stand") == 0 || strcmp(command_buffer, "rn st") == 0) runStandPose(1);
        else if(strcmp(command_buffer, "rn wv") == 0) { currentCommand = "wave"; runWavePose(); }
        else if(strcmp(command_buffer, "rn dn") == 0) { currentCommand = "dance"; runDancePose(); }
        else if(strcmp(command_buffer, "rn sw") == 0) { currentCommand = "swim"; runSwimPose(); }
        else if(strcmp(command_buffer, "rn pt") == 0) { currentCommand = "point"; runPointPose(); }
        else if(strcmp(command_buffer, "rn pu") == 0) { currentCommand = "pushup"; runPushupPose(); }
        else if(strcmp(command_buffer, "rn bw") == 0) { currentCommand = "bow"; runBowPose(); }
        else if(strcmp(command_buffer, "rn ct") == 0) { currentCommand = "cute"; runCutePose(); }
        else if(strcmp(command_buffer, "rn fk") == 0) { currentCommand = "freaky"; runFreakyPose(); }
        else if(strcmp(command_buffer, "rn wm") == 0) { currentCommand = "worm"; runWormPose(); }
        else if(strcmp(command_buffer, "rn sk") == 0) { currentCommand = "shake"; runShakePose(); }
        else if(strcmp(command_buffer, "rn sg") == 0) { currentCommand = "shrug"; runShrugPose(); }
        else if(strcmp(command_buffer, "rn dd") == 0) { currentCommand = "dead"; runDeadPose(); }
        else if(strcmp(command_buffer, "rn cb") == 0) { currentCommand = "crab"; runCrabPose(); }
        else if (strcmp(command_buffer, "subtrim") == 0 || strcmp(command_buffer, "st") == 0) {
          Serial.println("Subtrim values:");
          for (int i = 0; i < 8; i++) {
            Serial.print("Motor "); Serial.print(i); Serial.print(": ");
            if (servoSubtrim[i] >= 0) Serial.print("+");
            Serial.println(servoSubtrim[i]);
          }
        }
        else if (strcmp(command_buffer, "subtrim save") == 0 || strcmp(command_buffer, "st save") == 0) {
          Serial.println("Copy and paste this into your code:");
          Serial.print("int8_t servoSubtrim[8] = {");
          for (int i = 0; i < 8; i++) {
            Serial.print(servoSubtrim[i]);
            if (i < 7) Serial.print(", ");
          }
          Serial.println("};");
        }
        else if (strncmp(command_buffer, "subtrim reset", 13) == 0 || strncmp(command_buffer, "st reset", 8) == 0) {
          for (int i = 0; i < 8; i++) servoSubtrim[i] = 0;
          Serial.println("All subtrim values reset to 0");
        }
        else if (strncmp(command_buffer, "subtrim ", 8) == 0 || strncmp(command_buffer, "st ", 3) == 0) {
          const char* params = (command_buffer[1] == 't') ? command_buffer + 3 : command_buffer + 8;
          int trimMotor, trimValue;
          if (sscanf(params, "%d %d", &trimMotor, &trimValue) == 2) {
            if (trimMotor >= 0 && trimMotor < 8) {
              if (trimValue >= -90 && trimValue <= 90) {
                servoSubtrim[trimMotor] = trimValue;
                Serial.print("Motor "); Serial.print(trimMotor); Serial.print(" subtrim set to ");
                if (trimValue >= 0) Serial.print("+");
                Serial.println(trimValue);
              } else {
                Serial.println("Subtrim value must be between -90 and +90");
              }
            } else {
              Serial.println("Invalid motor number (0-7)");
            }
          }
        }
        else if (strncmp(command_buffer, "all ", 4) == 0) {
             if (sscanf(command_buffer + 4, "%d", &angle) == 1) {
                 for (int i = 0; i < 8; i++) setServoAngle(i, angle);
                 Serial.print("All servos set to "); Serial.println(angle);
             }
        }
        else if (sscanf(command_buffer, "%d %d", &motorNum, &angle) == 2) {
             if (motorNum >= 0 && motorNum < 8) {
                 setServoAngle(motorNum, angle);
                 Serial.print("Servo "); Serial.print(motorNum); Serial.print(" set to "); Serial.println(angle);
             } else {
                 Serial.println("Invalid motor number (0-7)");
             }
        }
        buffer_pos = 0;
      }
    } else if (buffer_pos < sizeof(command_buffer) - 1) {
      command_buffer[buffer_pos++] = c;
    }
  }
}

// Function to update the robot's face
void updateFaceBitmap(const unsigned char* bitmap) {
  display.clearDisplay();
  display.drawBitmap(0, 0, bitmap, 128, 64, SSD1306_WHITE);
  display.display();
}

uint8_t countFrames(const unsigned char* const* frames, uint8_t maxFrames) {
  if (frames == nullptr || frames[0] == nullptr) return 0;
  uint8_t count = 0;
  for (uint8_t i = 0; i < maxFrames; i++) {
    if (frames[i] == nullptr) break;
    count++;
  }
  return count;
}
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

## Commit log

2026-02-09 Add Sesame Studio animation tool
    Introduces Sesame Studio, a Python-based GUI for composing robot animations and generating C++ code for the Sesame Robot. Includes documentation and initial implementation with servo input, frame seq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
2026-03-26 Revise README for ESP32-based Sesame project
    Updated project description and hardware requirements to reflect the use of ESP32 and PCA9685. Revised features and added a warning about the repository's construction status.
2026-03-26 Add wiring guide documentation and assets
    Introduces a new wiring-guide section with detailed instructions for wiring the Sesame Robot, including guides for S2 Mini and Distro Board setups. Adds related images and updates the main README to 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
2026-03-26 Revamp README with badges and improved build instructions
    Added project badges for license, microcontroller, firmware, IDE, and GitHub stats. Reorganized and clarified build instructions, including step-by-step getting started guide, links to BOM, printing,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
2026-03-26 Add README files for PCB, BOM, and 3D printing guides
    Added initial README.md files for hardware/PCB and hardware/printing directories, providing overviews for schematics and 3D printing instructions. Expanded hardware/bom/README.md with rough component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
2026-03-26 [WIP] Add comprehensive Sesame Robot build guide with images
    Expanded the build guide in docs/build-guide/README.md to include detailed step-by-step assembly instructions, wiring, calibration, and final checks for the Sesame Robot. Added numerous illustrative 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
2026-03-26 Fix formatting and link in README files
    Restores missing horizontal rule in the main README and corrects the relative path for the wiring guide link in the build guide README.
2026-03-26 Revise hardware README with detailed build guide
    Expanded the hardware/README.md to include a directory guide, build path options, step-by-step getting started instructions, and links to supporting documents. This update clarifies the hardware stac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
2026-03-26 Update 3D printing guide
    Expanded the README to include a support requirements table for each component, specific print settings, and visual guides for manual support placement and joint orientation. This provides clearer in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
2026-03-26 Add Sesame Distro Board PCB files
    Added Gerber archive, schematic, and layout images for the Sesame Distro Board. Updated README with board details, sponsor info, and ordering instructions for PCB fabrication.
2026-03-26 Add printing asset images for hardware
    Added four new PNG images to hardware/printing/assets: joints-orientation, sliced-topcover, topcover-supports1, and topcover-supports2. These assets are likely used for documentation or visualization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
2026-03-26 Update CAD README
    Expanded the README to clarify available CAD formats, provide guidance for editing with free tools, and add tips for remixing and maintaining design files. Also redirected users seeking STL files to 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
2026-03-26 Revamp BOM documentation
    Expanded and reorganized the Bill of Materials README to provide detailed tables for all required components, wiring options, power sources, connectors, fasteners, 3D printed parts, and recommended t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
2026-03-26 Revamp build guide
    Expanded the Sesame Robot build guide with a clear phased workflow, detailed checklists, and step-by-step instructions for each assembly stage. Added tables, tips, warnings, and troubleshooting advice to improve clarity and reduce common errors. The guide now covers parts gathering, wiring, hardware pre-assembly, main assembly, calibration, and final firmware flashing, making the build process more organized and beginner-friendly.
2026-03-26 Expand wiring guide
    Added a section describing two wiring strategies (S2 Mini/hand wiring and Sesame Distro Board/ESP32-DevKitC-32E) to help users choose based on their needs. Included references to wiring diagrams for both methods and clarified instructions. Replaced PCBway sponsorship details with a link to the hardware documentation for more information.
2026-03-26 Update hardware and wiring docs with improved images and links
    Replaced markdown image syntax with HTML <img> tags for better control over image display in wiring and PCB guides. Updated BOM PCB link to reference local documentation. Revised printing guide to include STL file links and note multiple top cover styles. Minor grammar and formatting improvements throughout hardware documentation.
2026-03-26 Add v71 STL files for frame, joints, and covers
    Introduces new 3D printable STL files for version 71, including bottom cover, internal frame, femur and foot joints, and multiple top cover styles. These files support updated hardware designs for pr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
    [Bottom-Cover-v71.stl, Interna-Frame-v71.stl, femur-joint-L1-v71.stl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]
2026-03-26 Add PCB image and update servo comment
    Added pcbs.png to hardware/pcb directory. Updated a comment in the firmware to clarify servo pulse width mapping.
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2026-03-26 Fixed pcb README file
2026-03-26 Fix False Pin Number on S2 Mini Guide
    https://github.com/dorianborian/sesame-robot/issues/4#issue-3823691873
2026-03-26 Fix little typo in PCB README to render image
    "L" should be "l" to match the name of the image file.
2026-03-26 Document 2× 10440 Li-ion + AAA holder battery option
    Updated build, wiring, and BOM documentation to include details and recommendations for using 2× 10440 Li-ion cells in a 2× AAA holder as a battery option. Added notes on fit, wiring, charging, and sourcing to guide users considering this alternative.
    https://github.com/dorianborian/sesame-robot/issues/3
2026-03-26 Update README with Sesame Distro Board V1 Information
    Added caution note about the Sesame Distro Board V1 issues and recommended S2 Mini approach until V2 is released.
2026-03-26 Update README with note for distro board V1
    Added caution note regarding issues with V1 of the Sesame distro board and recommended alternatives until V2 is released.
2026-03-26 Update build guide for top cover styles and add images
    Expanded the build guide to cover both Enclosed and Original top cover assembly steps, including wiring and installation instructions. Added new images for display wiring, display insertion, securing the display, and switch installation. Corrected screw specification for securing the bottom cover.
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2026-03-26 Add and update STL files for top cover styles and hats
    Added new STL files for magnetic hats and various top cover styles, including enclosed and cat variants. Updated file names for consistency and removed obsolete files. Added a README describing each 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
    [magnetic-chainsaw-hat.stl, magnetic-modular-mount-hat.stl, sesame-top-cover-enclosed-cat.stl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]
2026-03-26 Update affected STL files to v80
    [Bottom-Cover-v71.stl, Bottom-Cover-v80.stl, Interna-Frame-v71.stl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]
2026-03-26 Add Correct Top cover file for enclosed cat
    https://github.com/dorianborian/sesame-robot/issues/12
    [sesame-top-cover-enclosed-cat.stl]
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2026-03-26 Update joints to v90
    Updated all joints to design version 90. Debossed text and details are now significantly larger to improve print tolerance. Resolves Issue #20
    [femur-joint-L1-v71.stl, femur-joint-L2-v71.stl, femur-joint-R1-v71.stl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]
2026-03-26 Update CAD source files to v91
    Major improvements to overall printability of the design, clearance, and various other issues. Main changes:
    Increased wall thickness on top cover for printing and structural support. #16
    Increased font size for debossed details on all joints to account for issue #20
    Relocated mounting holes for the top cover to improve Distro Board V1 and V2 clearance (V2 coming soon)
    Cleaned up the internal mounting of the OLED display for the enclosed top cover.
2026-03-26 Update misc stl to v90
    [Internal-Frame-v80.stl, bottom-cover-v90.stl, internal-frame-v90.stl]
2026-03-26 Update Enclosed top cover to v91
    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
    [sesame-top-cover-enclosed-v80.stl, sesame-top-cover-enclosed-v91.stl]
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2026-03-26 Update Build Guide Photos
    Fix screw dimensions to normalized M2x5mm
2026-03-26 Organize PCB files and add distro-v2 artifacts
    Move existing V1 PCB assets into hardware/pcb/distro-v1 (Gerber_Sesame-Distro-Board_PCB_Sesame-Distro-Board_V1.zip and Schematic_Sesame-Distro-Board.png) and add V2 manufacturing files under hardware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
    [BOM_Sesame-Distro-V2.csv, PickAndPlace_PCB_Sesame-Distro-V2.csv]
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2026-03-26 fix: typo in rocker power switch model number
    I believe the rocker switches are KCD1s
2026-03-26 Update all hardware to v100
    Update source hardware files, links and all stl print files to v100 revision.
    v100 hardware changes:
    Overall frame length has been increased by 0.25in to account for V2 distro board and wire sizing. Top cover ear revs have been migrated and updated. Various other changes including hole positioning a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
    [Top-Cover-Cat-v100.stl, Top-Cover-Enclosed-v100.stl, Top-Cover-No-Ears-v100.stl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]
2026-03-26 fix(bom): make link destination explicit and rename column to Source
2026-03-26 PCB BOM Part number and item specification
    Fixed part number and item specification mentioned in issues #42 #43 #44
    [BOM_Sesame-Distro-V2.csv]
2026-03-26 Update Hardware to V117
    Hardware update v117!
    Fixed issue where M2.5x5mm screws don't reach the servo motor shaft when inserted into hip joint.
    Fixed servo horns pressing into hip joints at a weird angle, adding small lifted area to account for uneven servo horn shape.
    Improved tolerences and fitment.
    Updated bottom plate to accept M2x5mm. All screws now use M2x5mm and should fit.
    [Bottom-Cover-v117.stl, Internal-Frame-v117.stl, L1-v117.stl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]
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2026-03-26 Distro-v2 BOM fix
    [BOM_Sesame-Distro-V2.csv]
2026-03-26 Fix duplicate Tutorial button
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2026-04-09 Revamp forward and reverse walk cycle + Bitmaps
    Replaced placeholder face bitmap arrays with actual 128x64px bitmap data for various face expressions in sesame-firmware-S2-mini.ino. Also updated comments for I2C and servo pin definitions to be more generic for the S2 Mini board.
    Revamped walk cycle for consistency, fixed reverse walk cycle for going backwards.
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2026-04-09 Update README with detailed pin configuration tables
    Expanded the documentation to include explicit pin mapping tables for both the Lolin S2 Mini (ESP32-S2) and Sesame Distro Board (ESP32-WROOM32). This provides clearer guidance for hardware setup and eases porting to other ESP32 variants.
    https://github.com/dorianborian/sesame-robot/issues/14
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2026-04-09 Revamp captive portal UI and controls
    Overhauled the captive-portal HTML/CSS/JS to modernize the UI and add features: updated page title and responsive layout, new visual theme vars and polished button/section styles, and a desktop-friendly column layout. Added a command queue (max 3) with status indicator and queue management to throttle commands, plus motor locking during animations. Introduced a Manual Motor Control panel with 8 sliders and lock indicator, expanded Settings with grouped sections, motor speed and debugMode options, and theme color selection (persisted to localStorage). Gamepad support and polling were implemented with button/axis bindings and UI connection state. Adjusted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
2026-04-09 Add per-servo subtrim and CLI commands #17
    Introduce servoSubtrim[8] to store per-servo angle offsets and apply them in setServoAngle (angle+subtrim is constrained to 0–180). Add serial CLI commands and aliases: 'subtrim'/'st' to list values, 'subtrim save'/'st save' to print an initializer for copying into code, 'subtrim reset'/'st reset' to zero all trims, and 'subtrim <motor> <value>'/'st <motor> <value>' to set an individual motor's trim (validated to -90..+90). These changes make it easier to fine-tune servo neutral positions at runtime. Closes Issue #17
    [sesame-firmware-main.ino]
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2026-04-09 Add PSRAM detection and heap control
    Detect and manage PSRAM usage and add optional heap control. Conditionally include esp_heap_caps.h and define HAS_EXTMEM_HEAP_CONTROL. Introduce FORCE_DISABLE_PSRAM_HEAP (default true) to hard-disable PSRAM-backed heap by default to avoid instability. Add PSRAM status variables, refreshPsramStatus() and configurePsram() to detect PSRAM, print diagnostics, and enable/disable extmem heap (using heap_caps_malloc_extmem_enable when available). Expose PSRAM fields in the status API response and call configurePsram() from setup(). Also rename access-point SSID from "Sesame-Controller-BETA" to "Sesame-Controller".
    [sesame-firmware-main.ino]
2026-04-09 Firmware README: add ESP32-S3 & troubleshooting
    Clarify board selection and per-board settings: split Sesame Distro V1/V2 into ESP32 Dev Module and ESP32S3 Dev Module, and reorganize the "Configure board settings" section with Lolin S2 Mini and Distro V2 (ESP32-S3) specific options (USB CDC, Flash Mode, Partition Scheme, upload speed). Improve troubleshooting: add Linux USB permission instructions (dialout group), note that USB CDC On Boot is required for S3 boards to appear after reset, and suggest trying a custom AP password if devices can't connect. Minor wording and formatting adjustments to make setup steps clearer.
2026-04-09 Update README.md to include warning for ESPServo
    Addresses issue #53 to specify esp32servo library version.

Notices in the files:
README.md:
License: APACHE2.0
